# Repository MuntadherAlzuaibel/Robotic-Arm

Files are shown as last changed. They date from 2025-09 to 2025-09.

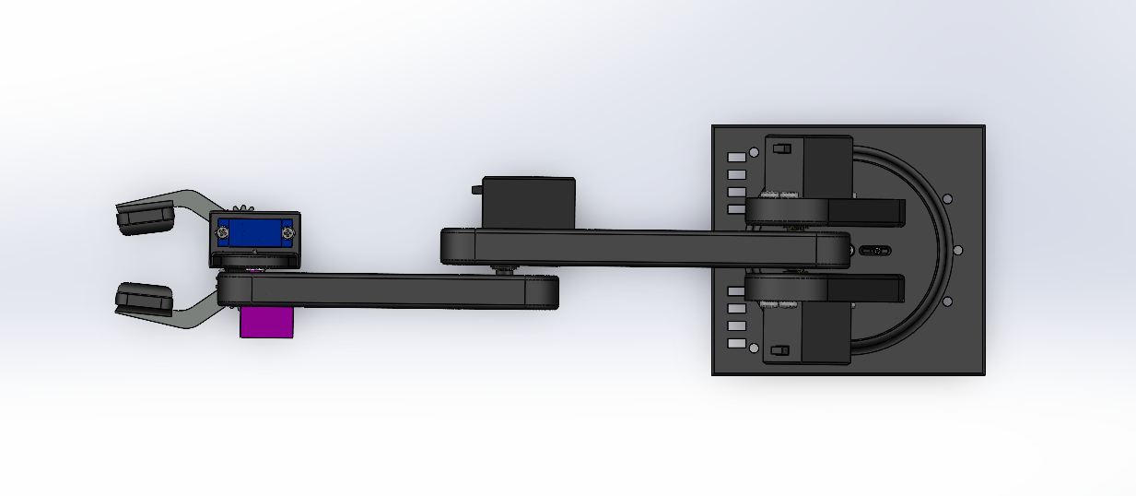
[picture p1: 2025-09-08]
Pics/TopView Torque Analysis.png

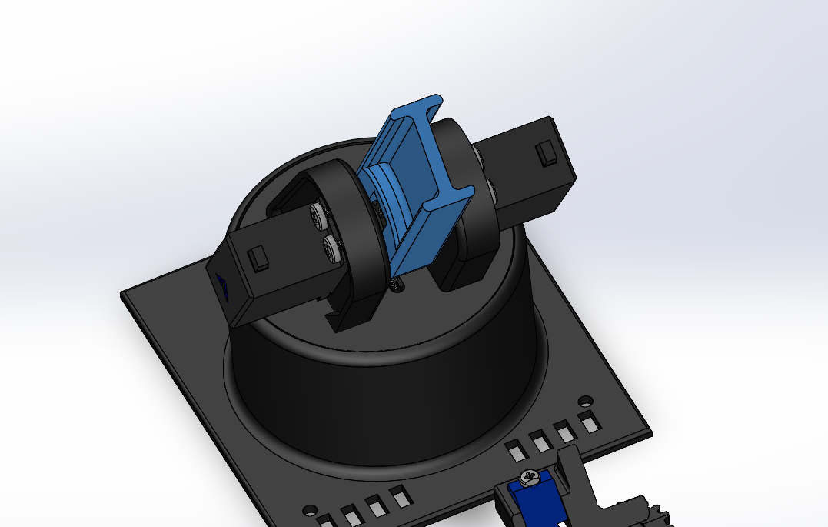
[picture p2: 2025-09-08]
Pics/UpperArm Hbeam.png

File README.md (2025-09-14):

# 4-DOF Robotic Arm with Claw

This project documents the design and implementation of a **4-DOF robotic arm** capable of lifting payloads up to 500 g.  
It covers **mechanical design**, **electronics integration**, and **software development** on the ESP32 with simplified forward kinematics for wrist leveling.

---

## 📂 Project Structure
- **Mechanical/** – SolidWorks models, CAD renders
- **Electronics/** – Wiring diagrams, power setup notes
- **Software/** – ESP32 C++ code (PlatformIO, PCA9685 control)
- **Docs/** – Torque analysis, lessons learned, results
- **Images/** – Photos and testing screenshots

---

## ⚙️ Features
- Dual MG996R shoulder servos with torque sharing  
- Gear-driven claw with gripping lips for secure grasping  
- Wrist auto-leveling to keep claw parallel to the ground  
- Modular 3D-printed H-beam links for strength and low weight  
- Serial keyboard control interface (manual testing and debugging)

---

## 🔧 Hardware Setup
1. **Power**
   - 6×AA battery pack (~9 V) → PCA9685 `V+` and `GND` rails  
   - ESP32 `GND` tied to PCA9685 `GND` for common reference   

2. **Wiring**
   - Servos connected to PCA9685 channels:
     - Base = Channel 0  
     - Shoulder (Right + Left mirrored) = Channels 1 & 2 respectively 
     - Elbow = Channel 3  
     - Wrist = Channel 4  
     - Claw = Channel 5  
   - ESP32 connected to PCA9685 via I²C (`SDA = 21`, `SCL = 22`)  

3. **Assembly**
   - Mount servos into 3D-printed H-beam arms  
   - Use screws as seen in model 
   - Ensure claw gear teeth are aligned before powering up  

---

## 💻 Software Setup
   - Install [PlatformIO](https://platformio.org/) (recommended) or Arduino IDE.  

---

## 🎮 Controls

The robotic arm can be manually operated via **serial keyboard input**.  

| Key | Action |
|-----|---|
| `w` | Shoulder up |
| `s` | Shoulder down |
| `a` | Base rotate left |
| `d` | Base rotate right  |
| `q` | Elbow up |
| `e` | Elbow down |
| `z` | Wrist up |
| `c` | Wrist down |
| `r` | Claw open |
| `f` | Claw close |
| `p` | Park pose (reset)  |

- The **Park pose** initializes all joints to a neutral, safe position.  
- The **wrist auto-leveling function** ensures the claw remains parallel to the ground whenever the shoulder or elbow moves.

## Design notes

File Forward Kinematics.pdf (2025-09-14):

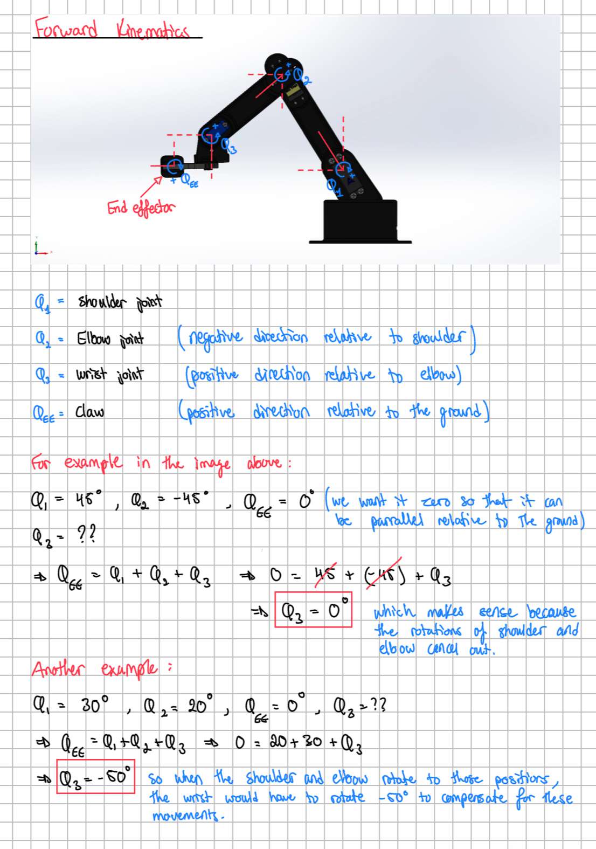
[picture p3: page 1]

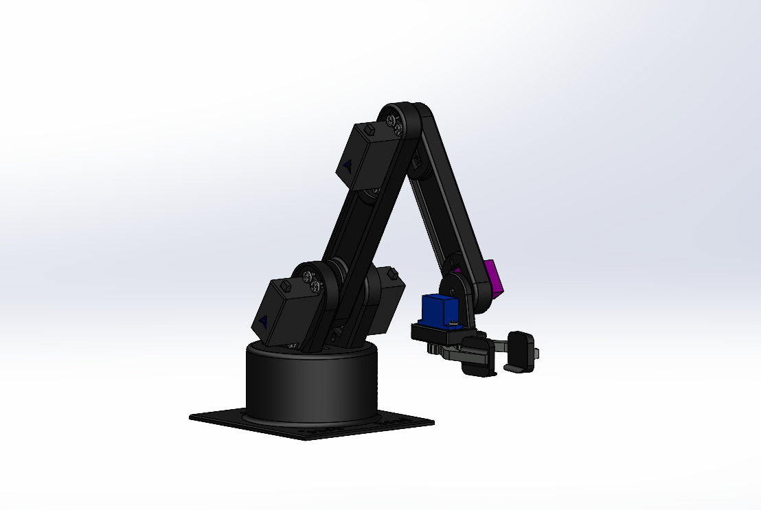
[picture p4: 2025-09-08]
Pics/Main2.png

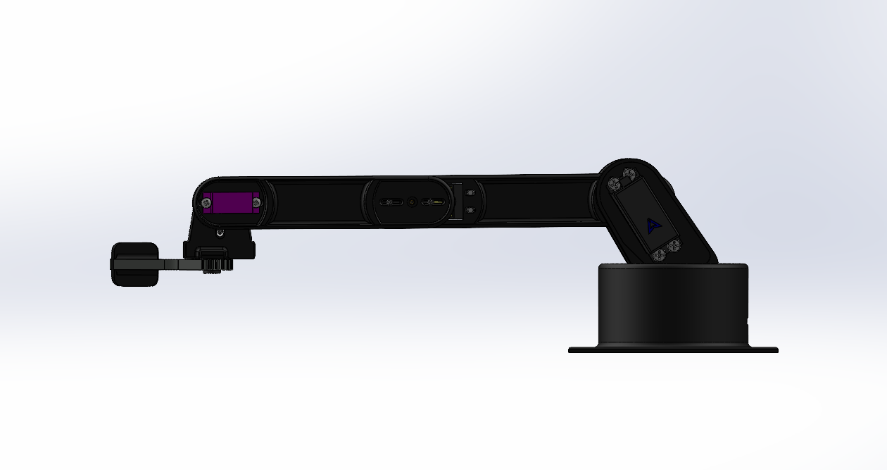
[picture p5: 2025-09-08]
Pics/V4 Torque analysis.png

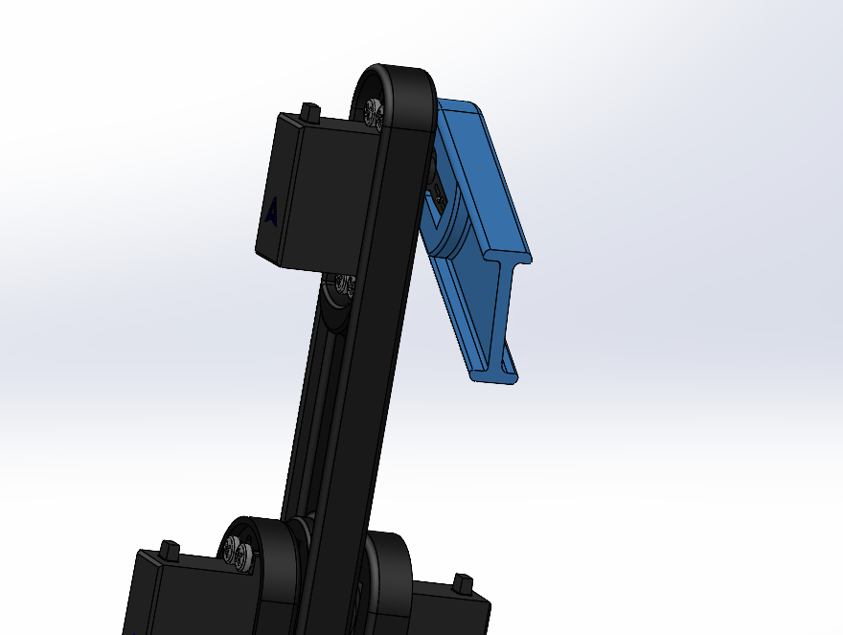
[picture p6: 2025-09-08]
Pics/Forearm Hbeam.png

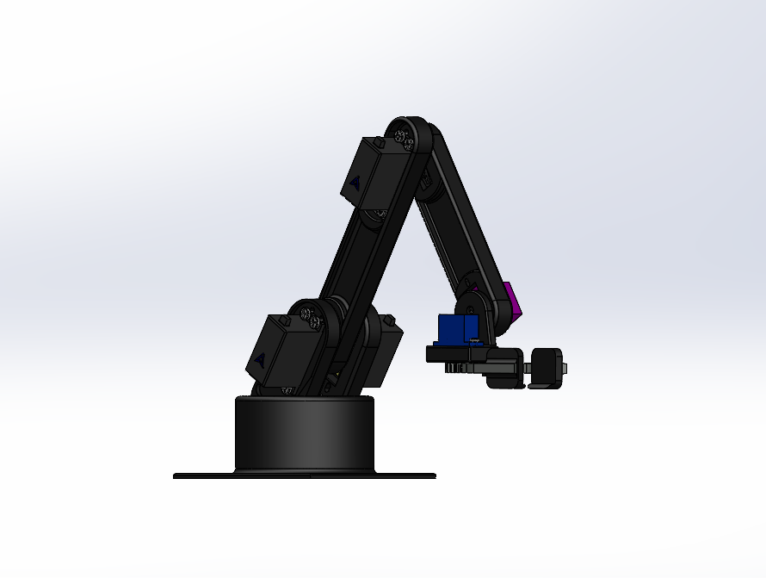
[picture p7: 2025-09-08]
Pics/Default view.png

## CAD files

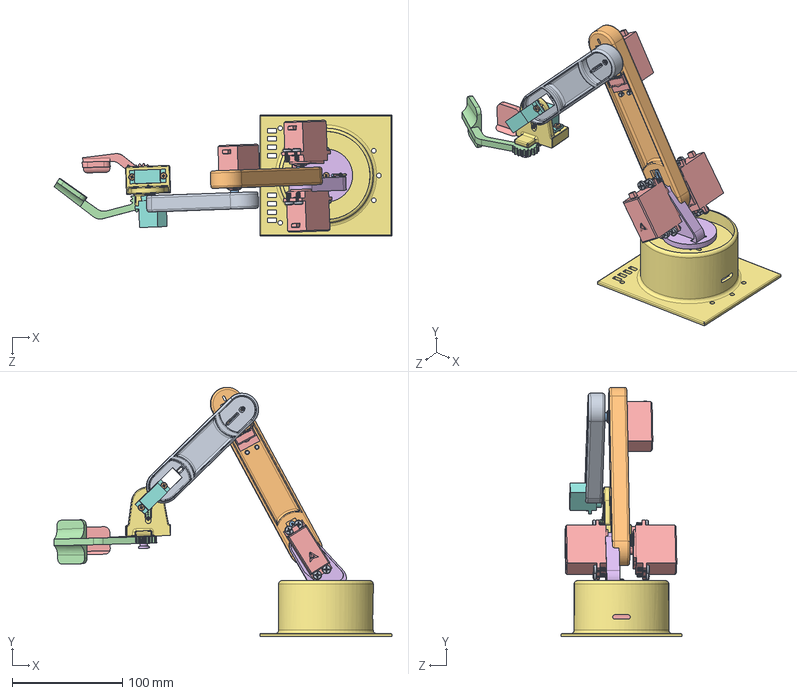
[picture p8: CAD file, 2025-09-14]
Parts/Robotic Arm.SLDASM
307.0 x 226.5 x 110.0 mm
Base
Shoulder
MG996R Servo Dummy x 4
Dummy Servo Horn 1 x 2
MG996r Dummy Servo Horn x 4
UpperArm
Forearm
SG90 Servo Dummy x 2
Wrist
Claw gear lock
Right Servo Gripper
Left Gripper
M2 x 8mm - 90380A327 x 12
M3 x 6mm - 92005A116 x 5
M4 x 8mm - 92005A218 x 16

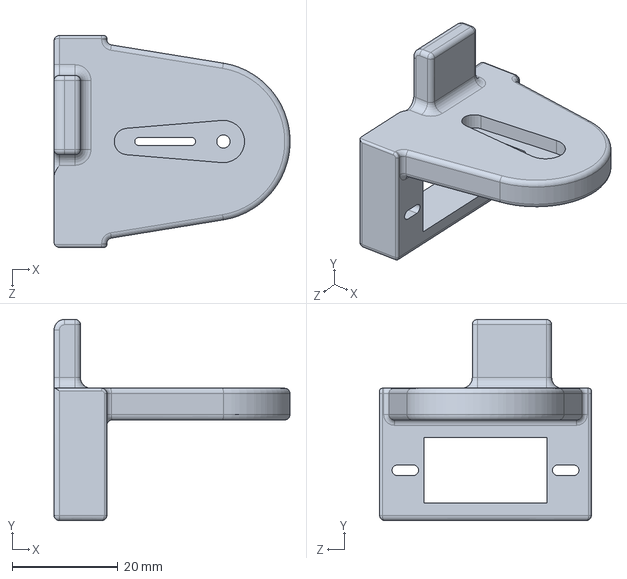
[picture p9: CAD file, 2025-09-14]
Parts/Wrist.SLDPRT
44.6 x 38.0 x 40.0 mm

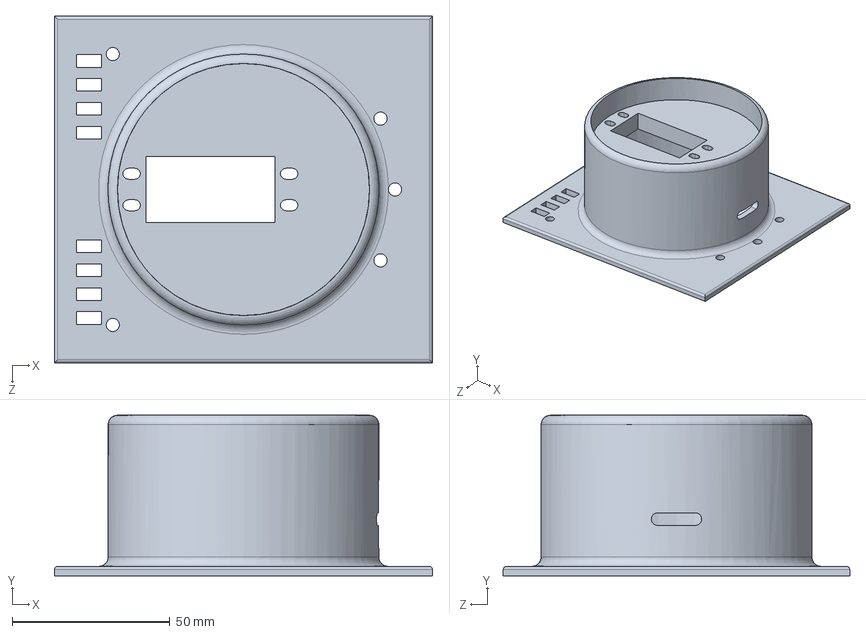
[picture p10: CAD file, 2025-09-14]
Parts/Base.SLDPRT
120.0 x 51.0 x 110.0 mm

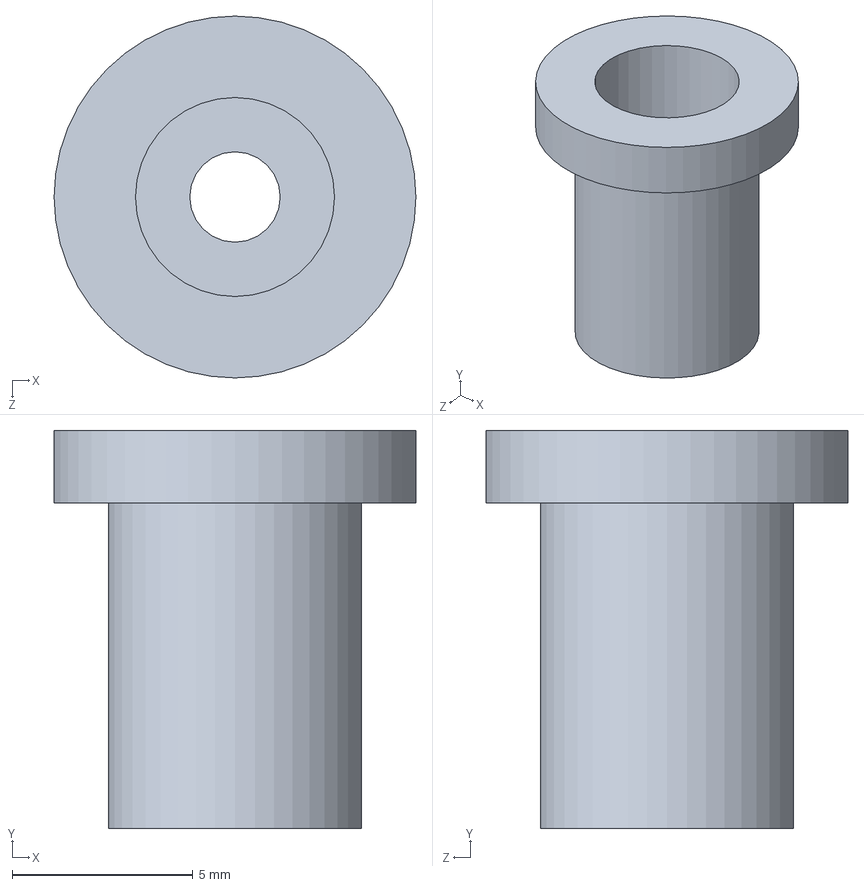
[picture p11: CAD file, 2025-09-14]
Parts/Claw gear lock.SLDPRT
10.0 x 11.0 x 10.0 mm

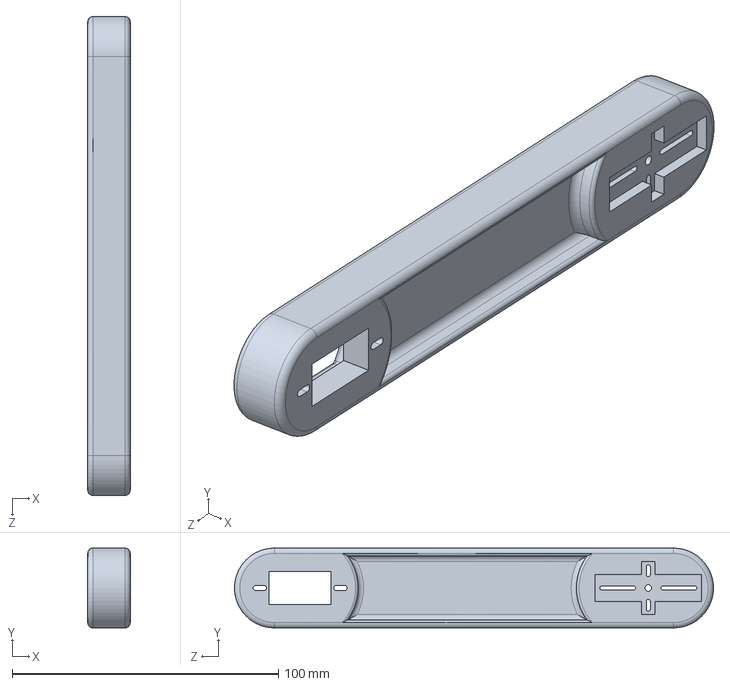
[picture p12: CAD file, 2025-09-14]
Parts/UpperArm.SLDPRT
16.0 x 30.0 x 180.0 mm

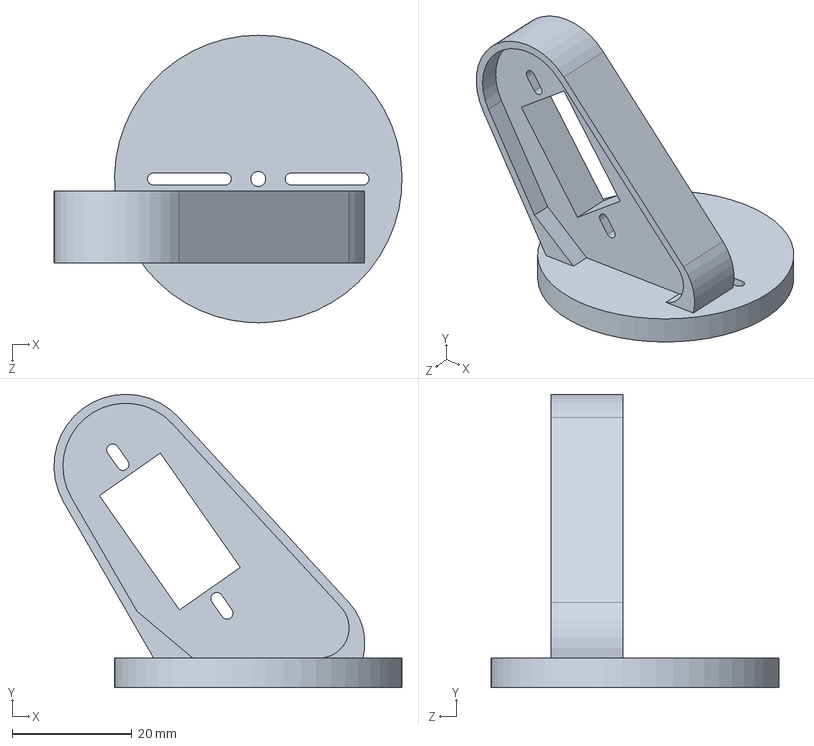
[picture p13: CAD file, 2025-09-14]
Parts/Shoulder.SLDPRT
58.1 x 49.0 x 48.0 mm

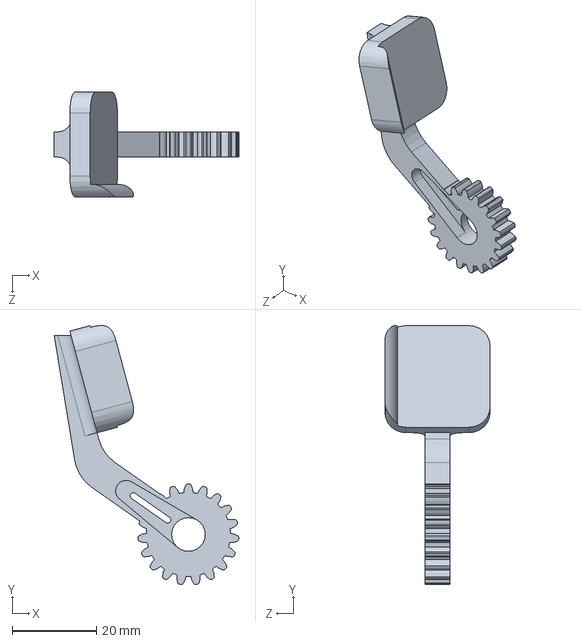
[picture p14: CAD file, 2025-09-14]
Parts/Right Servo Gripper.SLDPRT
43.9 x 61.5 x 25.0 mm

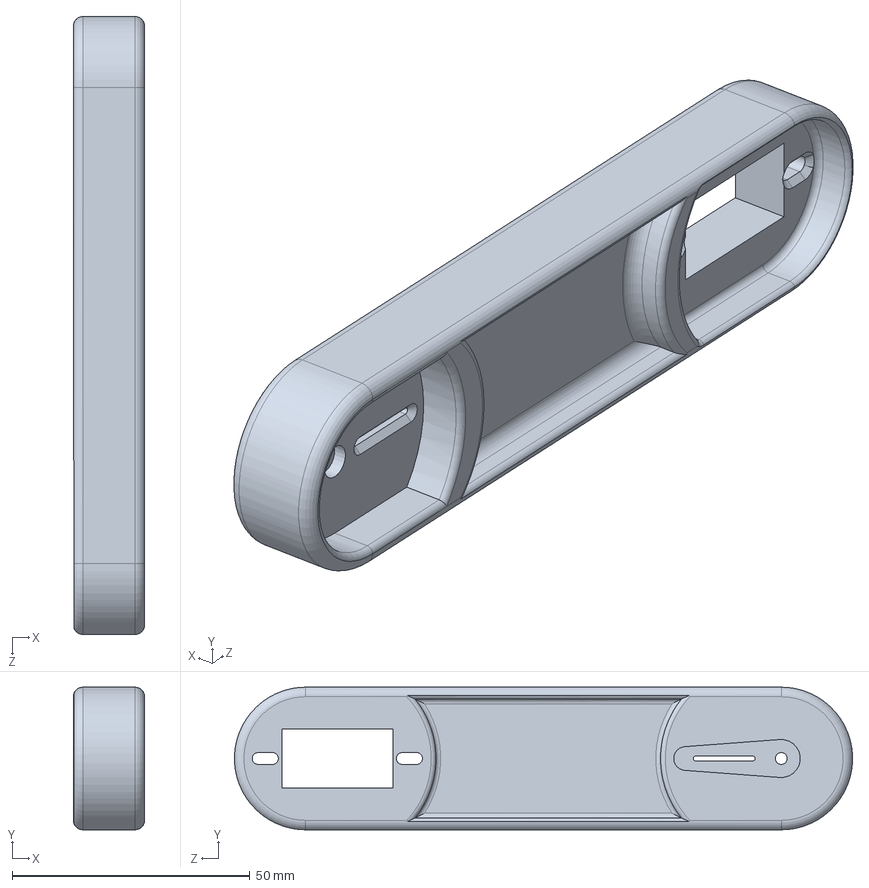
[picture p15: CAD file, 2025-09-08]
Parts/Forearm.SLDPRT
15.0 x 30.0 x 130.0 mm

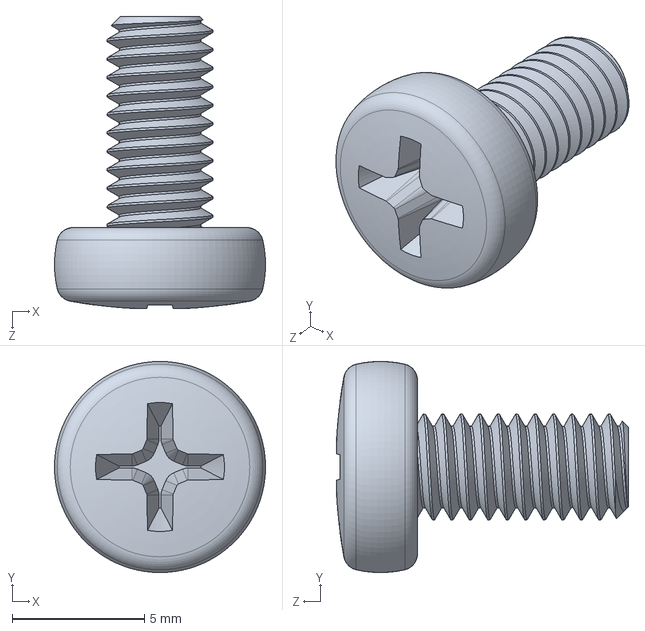
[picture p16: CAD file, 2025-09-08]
Parts/M4 x 8mm - 92005A218.SLDPRT
7.99 x 8.00 x 11.1 mm

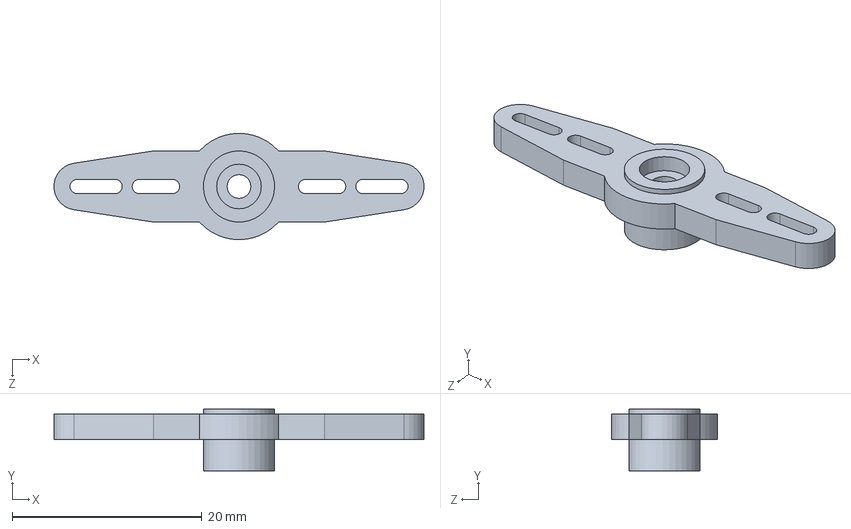
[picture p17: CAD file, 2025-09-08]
Parts/MG996r Dummy Servo Horn.SLDPRT
39.0 x 6.50 x 11.2 mm

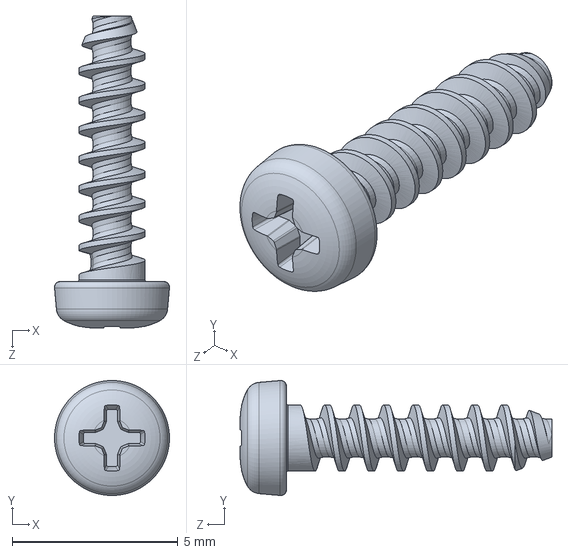
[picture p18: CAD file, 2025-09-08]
Parts/M2 x 8mm - 90380A327.SLDPRT
3.47 x 3.47 x 9.40 mm

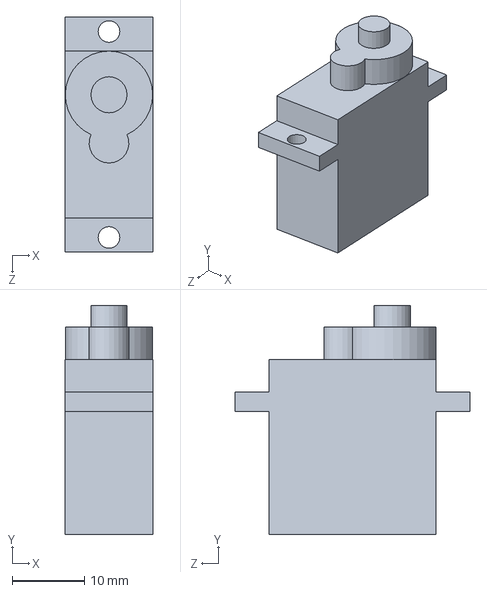
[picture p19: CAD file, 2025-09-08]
Parts/MG90S Servo Dummy.SLDPRT
12.2 x 31.7 x 32.5 mm

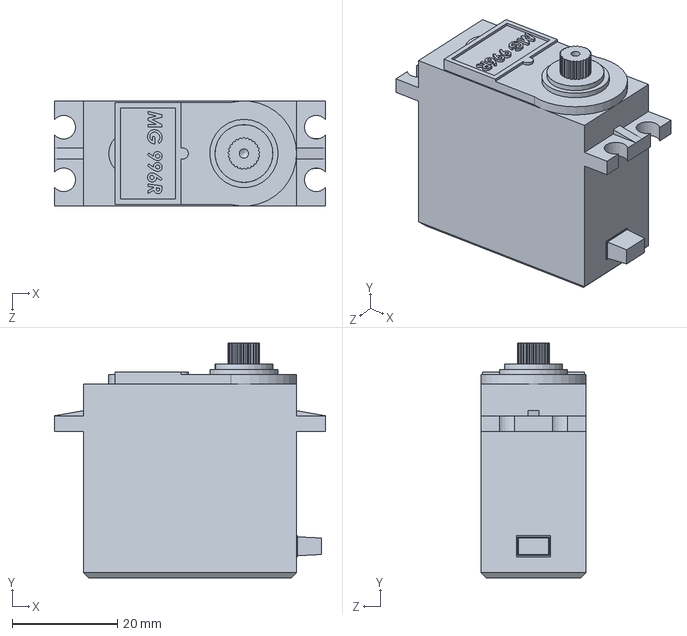
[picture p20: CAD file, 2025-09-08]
Parts/MG996R Servo Dummy.SLDPRT
51.5 x 44.6 x 20.0 mm

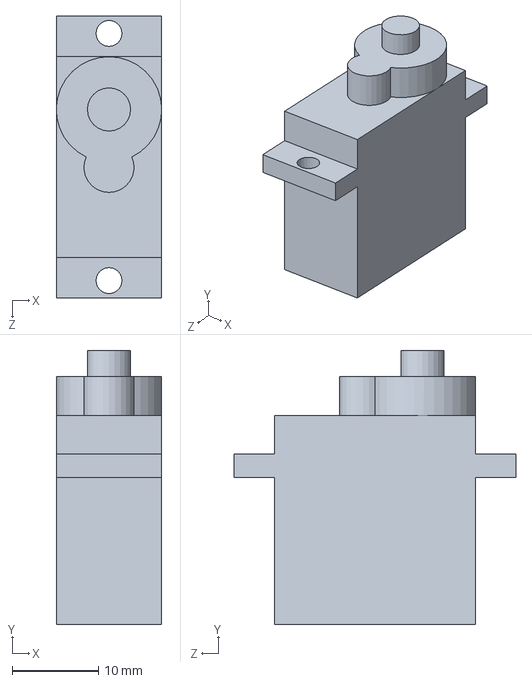
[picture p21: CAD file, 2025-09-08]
Parts/SG90 Servo Dummy.SLDPRT
12.2 x 31.7 x 32.6 mm

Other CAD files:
Parts/Left Gripper.SLDPRT
Parts/Dummy Servo Horn 1.SLDPRT
Parts/M3 x 6mm - 92005A116.SLDPRT
Parts/92005A061_Steel Pan Head Phillips Screw.SLDPRT
3D prints/Base.STL
3D prints/Claw gear lock.STL
3D prints/Forearm.STL
3D prints/Left Gripper.STL
3D prints/Right Servo Gripper.STL
3D prints/Shoulder.STL
3D prints/UpperArm.STL
3D prints/Wrist.STL

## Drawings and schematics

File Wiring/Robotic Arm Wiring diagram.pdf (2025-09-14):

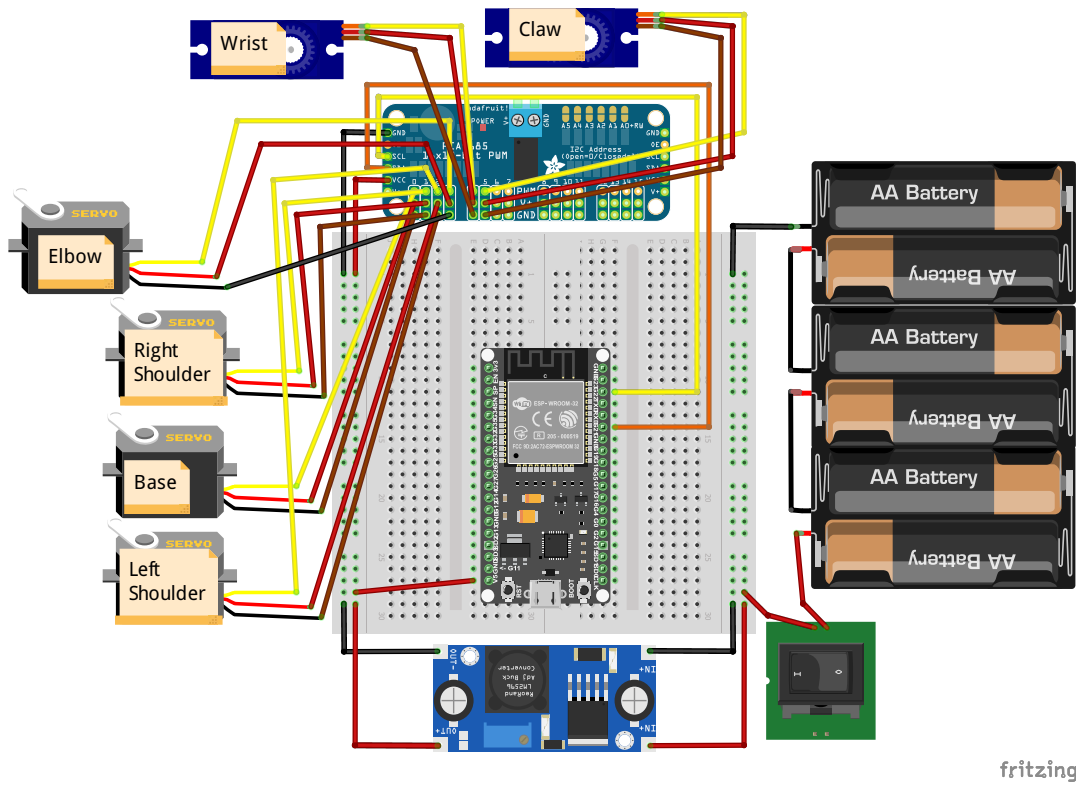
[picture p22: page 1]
Base; Right Shoulder; Left Shoulder; Elbow; Wrist; Claw

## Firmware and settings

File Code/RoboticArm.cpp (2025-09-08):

#include <Arduino.h>
#include <Wire.h>
#include <Adafruit_PWMServoDriver.h> // Include the Adafruit PWM Servo Driver library

Adafruit_PWMServoDriver Driver = Adafruit_PWMServoDriver(0x40);

#define SDA_PIN 21
#define SCL_PIN 22

#define base_channel 0
#define Rshoulder_channel 1
#define Lshoulder_channel 2
#define elbow_channel 3
#define wrist_channel 4
#define claw_channel 5

#define minUs 750 // Servo pulse width range
#define maxUs 2250 // Servo pulse width range

int angleToUs(int angle) // Convert angle (0–180) to pulse width in microseconds (for 50 Hz servo signal)
{
  // Ensure angle is within valid range to eliminate jitter
  if (angle < 0) angle = 0;
  if (angle > 180) angle = 180;

  return map(angle, 0, 180, minUs, maxUs); // Map angle to pulse width
}

void sendPWM(int channel, int angle)
{
  Driver.writeMicroseconds(channel, angleToUs(angle)); // Write duty cycle to servo channel
}

void setShoulder(int angle)
{
  sendPWM(Rshoulder_channel, angle);
  sendPWM(Lshoulder_channel, 180 - angle); // Invert left shoulder movement
}

void setup() 
{
  Serial.begin(115200); // Initialize serial communication
  Serial.println("Robotic Arm Initialized");

  /////////////////// Servo Driver Setup (PCA9685) /////////////////////

  Wire.begin(SDA_PIN, SCL_PIN); // Initialize I2C
  Driver.begin(); // Initialize the PCA9685
  Wire.setClock(100000);   // keep it slow (100 kHz) while debugging
  Driver.setPWMFreq(50); // Set frequency to 50 Hz for servos

  // Move servos to initial Parking positions
  //sendPWM(base_channel, 90); delay(100);   
  //setShoulder(0); delay(100);
  //sendPWM(elbow_channel, 180); delay(100);
  //sendPWM(wrist_channel, 40); delay(100);
  //sendPWM(claw_channel, 150); delay(100);
  delay(300);
}

// Global variables to store current angles
int baseAngle = 90; // Default base angle
int shoulderAngle = 0; // Default shoulder angle
int elbowAngle = 180; // Default elbow angle
int wristAngle = 40; // Default wrist angle
int clawAngle = 90; // Default claw angle

void loop()
{ 
  if (Serial.available()) 
  {
    Serial.print("Robot ready");
    char command = Serial.read(); 
    Serial.println(command);

    if (command == '\n' || command == '\r') return; // ignore line endings

    switch (command) 
    {
      case 'w':
        setShoulder(shoulderAngle += 5);
        Serial.println("Shoulder moved to " + String(shoulderAngle) + "°");
        break;

      case 's':
        setShoulder(shoulderAngle -= 5);
        Serial.println("Shoulder moved to " + String(shoulderAngle) + "°");
        break;

      case 'a':
        sendPWM(base_channel, baseAngle -= 5);
        Serial.println("Base rotated to " + String(baseAngle) + "°");
        break;

      case 'd':
        sendPWM(base_channel, baseAngle += 5);
        Serial.println("Base rotated to " + String(baseAngle) + "°");
        break;

      case 'q':
        sendPWM(elbow_channel, elbowAngle -= 5);
        Serial.println("Elbow moved to " + String(elbowAngle) + "°");
        break;

      case 'e':
        sendPWM(elbow_channel, elbowAngle += 5);
        Serial.println("Elbow moved to " + String(elbowAngle) + "°");
        break;
      
      case 'z':
        sendPWM(wrist_channel, wristAngle += 5);
        Serial.println("Wrist moved to " + String(wristAngle) + "°");
        break;
      
      case 'c':
        sendPWM(wrist_channel, wristAngle -= 5);
        Serial.println("Wrist moved to " + String(wristAngle) + "°");
        break;
      
      case 'r':
        sendPWM(claw_channel, clawAngle += 5);
        Serial.println("Claw moved to " + String(clawAngle) + "°");
        break;

      case 'f':
        sendPWM(claw_channel, clawAngle -= 5);  
        Serial.println("Claw moved to " + String(clawAngle) + "°");
        break;
        
      default:
        Serial.println("Invalid command. Use '0' to '4' to move the shoulder.");
        break;
    }
  }
}

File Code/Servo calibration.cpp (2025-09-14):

#include <Arduino.h>

// Servo pin & channel
#define SERVO_PIN      2
#define SERVO_CHANNEL  0

// PWM config (ESP32 ledc, 50 Hz, 16-bit resolution)
const int PWM_RES_BITS = 16;
const int DUTY_MIN     = 1638;   // ≈0.5 ms pulse (0°)
const int DUTY_MAX     = 8192;   // ≈2.5 ms pulse (180°)

// Convert angle (0–180) to duty cycle
inline int angleToDuty(int angle) {
  angle = constrain(angle, 0, 180);
  return map(angle, 0, 180, DUTY_MIN, DUTY_MAX);
}

void setup() {
  Serial.begin(115100);

  // Setup PWM channel
  ledcSetup(SERVO_CHANNEL, 50, PWM_RES_BITS);
  ledcAttachPin(SERVO_PIN, SERVO_CHANNEL);

  // Move servo to 0°
  ledcWrite(SERVO_CHANNEL, angleToDuty(90));
  Serial.println("Servo on pin 2 moved to 0°");
}

void loop() {
  // Nothing here — servo stays at 0°
}

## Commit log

2025-09-08 Initial upload of robotic arm project files
    [Base.SLDPRT, Base.STL, Claw gear lock.SLDPRT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]
2025-09-14 Update project with new files and major improvements
    Replaced outdated files with updated versions and added new components: SolidWorks models, wiring diagrams, ESP32 code, torque/load analysis, and improved README with setup instructions and control mappings.
    [92005A061_Steel Pan Head Phillips Screw.SLDPRT, Base.SLDPRT, Claw gear lock.SLDPRT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]
